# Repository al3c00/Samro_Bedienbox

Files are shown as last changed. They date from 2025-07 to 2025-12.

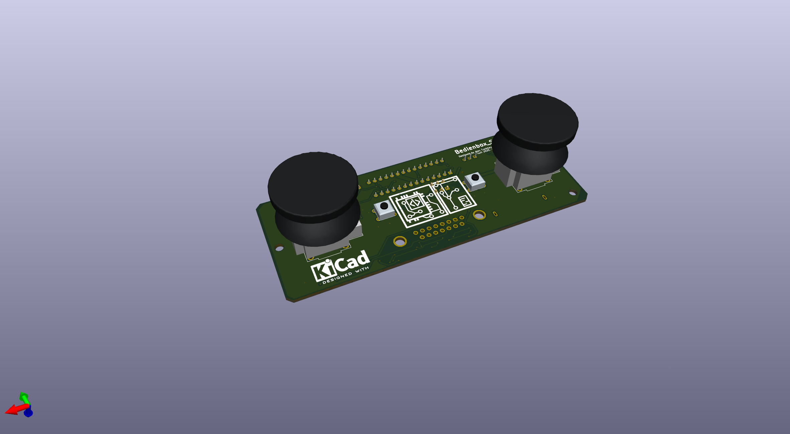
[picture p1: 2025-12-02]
hardware/ansicht_oben.png

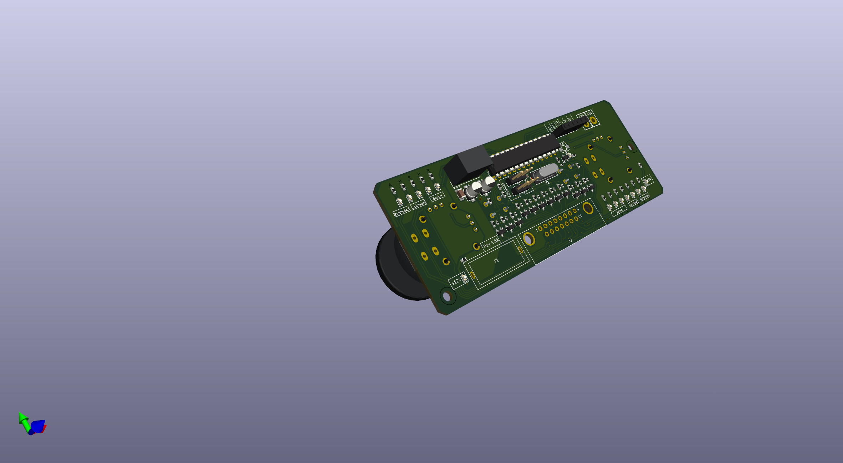
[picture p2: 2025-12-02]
hardware/ansicht_unten.png

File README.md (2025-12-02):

# Samro_Bedienbox

## Übersicht:
Dieses Repository beinhaltet PCB-Daten (Gerber-Dateien und ein KiCAD-Projekt) sowie den Quellcode für die Programmierung des verwendeten ATMega328.

## Hintergrund:
Dies ist eine Steuerungsbox, die die bestehende Steuerung eines Samro Offsett KK Kartoffelvollernters ergänzt. Die Standardbedienung der 20 Jahre alten Maschine weicht von moderneren Bedienunglayouts ab. Um mir als Fahrer, der bei einem Lohnunternehmer im Herbst etliche Stunden mit neuen Maschinen fährt, jeweils den Wechsel der Maschine zu erleichtern, wurde diese Bedienung konstruiert. Die Funktionsbelegung ähnelt der Grimme GBX 800, wie sie beim Lohnunternehmen Wyss-Wyss verwendet wird.

## Funktion:
### Übersicht
Die Kontaktschalter der Samro-Bedienbox ziehen das Signal auf Masse. Die Hardware der Box erkennt dies und sendet ein entprechendes Signal an die Hauptplatine der Maschine. Die zusätzliche Bedienbox ergänzt diese FUnktionsweise. An die Signalpins der Kontaktschalter werden Kabel gelötet welche mit der zusätzlichen Box verbunden werden. 
### Detailiert
Beispielhafte Darstellung der Funktionsweise an einer Funktion:

```mermaid
  graph TD;
  Pin_MC_Samro-->Joystick;
  Joystick-->2N7002_zusätzliche_Box;
  ATMega328-->2N7002_zusätzliche_Box;
  2N7002_zusätzliche_Box-->Masse;
  Joystick-->Masse;

style Joystick fill:#4CED57
```

Um die Verwendung von ISP auf der Platine zun ermöglichen dürfen ISP-Pins des ATMega328 nicht belegt werden. Dies hat zur Folge, dass nicht alle wichtigen Funktionen der Maschine auf einer zusätzlichen Box belegt werden können. Abhilfe wird mit Jumpern geschaffen. Von zwei ATMega328 Ausgangspins (PD1 und PD2) kann ausgewählt werden, ob das Signal den Bunker oder die Dammaufnahme ansteuern soll. Andere Belegungsänderungen sind während Laufzeit nicht möglich und müssen durch ändern des Quellcodes und Neukompilierung gemacht werden.

## Software:
Es gibt kein seperater Ordner der für den Quellcode benutzt wird. Die .ino-Datei beinhaltet alle Daten. 

## Hardware:
Im Hardware-Ordner finden sich die Schemas, Gerber-Dateien und das dazugehörige KiCAD-Projekt. 

## Programmierung des ATMega328:
### Es gibt viele verschiedene, sehr gute Artikel dazu. Ein Beispiel: https://www.brennantymrak.com/articles/programming-avr-with-arduino

|ATMEga328|Arduino|
|---|---|
|PC6|Pin 10|
|PB5|Pin 13|
|PB4|Pin 12|
|PB3|Pin 11|
+ In IDE (Arduino IDE oder Visual Micro in VS2022), wähle Arduino als ISP
+ Richtiger Chip mit korrekter Clock-Speed

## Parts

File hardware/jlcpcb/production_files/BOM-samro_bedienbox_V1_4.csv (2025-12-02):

Comment | Designator | Footprint | LCSC | Quantity
220 | R1,R10,R14,R17,R23,R24,R25,R26,R32,R36,R37,R4,R9 | R_0402_1005Metric | C1091 | 13
2N7002K | Q1,Q10,Q11,Q12,Q13,Q2,Q3,Q4,Q5,Q6,Q7,Q8,Q9 | SOT-23 | C114458 | 13
16MHz | Y1 | Crystal_SMD_HC49-SD | C12676 | 1
10k | R13,R16,R19,R20,R21,R22,R3,R31,R34,R35,R5,R7,R8,R82,R83,R84 | R_0603_1608Metric | C15401 | 16
20pF | C4,C5 | C_0402_1005Metric | C1554 | 2
100nF | C2 | C_0402_1005Metric | C1581 | 1
LED_Green | D27,D28 | LED_0603_1608Metric | C165982 | 2
ATmega328P-P | U1 | DIP-28_W7.62mm | C16653 | 1
1uF | C1 | C_1206_3216Metric | C1848 | 1
D-Sub_15Pins | J2 | D-SUB-DR-15PCG-AB | C19077347 | 1
LED_Red | D1,D10,D11,D12,D13,D2,D3,D4,D5,D6,D7,D8,D9 | LED_0603_1608Metric | C19171390 | 13
130 | R11,R12,R15,R18,R2,R27,R28,R29,R30,R33,R38,R39,R6,R80 | R_0603_1608Metric | C22796 | 14
15k | R85 | R_0603_1608Metric | C22809 | 1
470 | R79 | R_0603_1608Metric | C23179 | 1
Conn_01x06_Socket | J4 | PinSocket_1x06_P2.54mm_Vertical | C2832269 | 1
10uF | C3,C6 | CP_Elec_4x5.4 | C3343 | 2
Conn_01x03_Pin | J5,J6 | PinHeader_1x03_P2.54mm_Vertical | C49257 | 2
Fuseholder | F1 | Fuseholder_C58066 | C58066 | 1
SW_Push | SW5 | Button_L3.9_W3.0 | C720477 | 1
TSR1-2450E | U4 | Converter_DCDC_TRACO_TSR1-xxxxE_THT |  | 1
~ | U3 | Analog_Thumb_Joystick |  | 1
SW_Button_1 | SW1 | Button_DIP_DTS-62N |  | 1
~ | U2 | Analog_Thumb_Joystick |  | 1
SW_Button_2 | SW2 | Button_DIP_DTS-62N |  | 1

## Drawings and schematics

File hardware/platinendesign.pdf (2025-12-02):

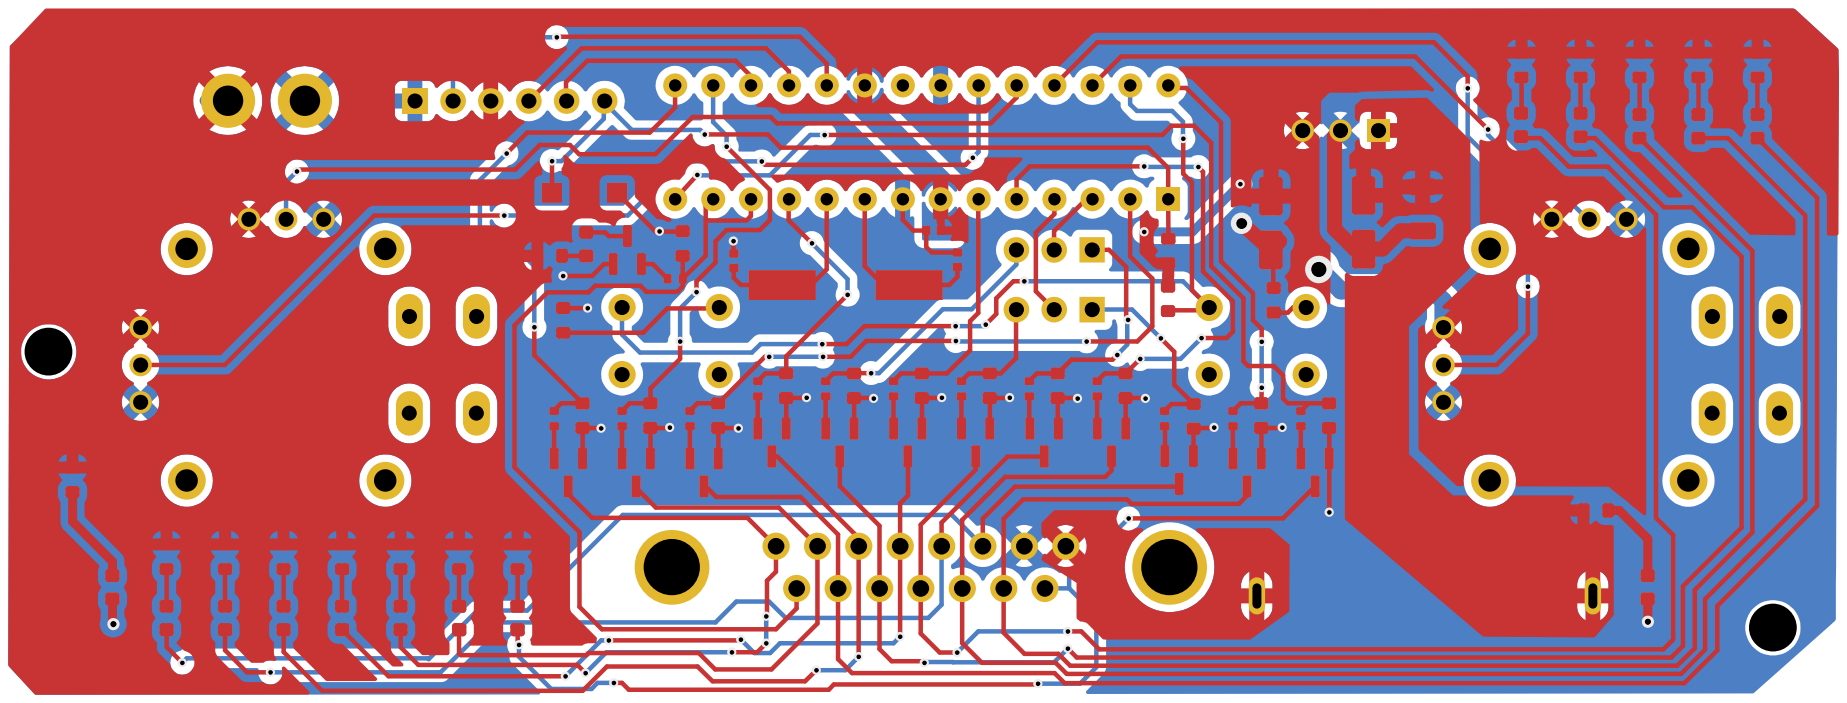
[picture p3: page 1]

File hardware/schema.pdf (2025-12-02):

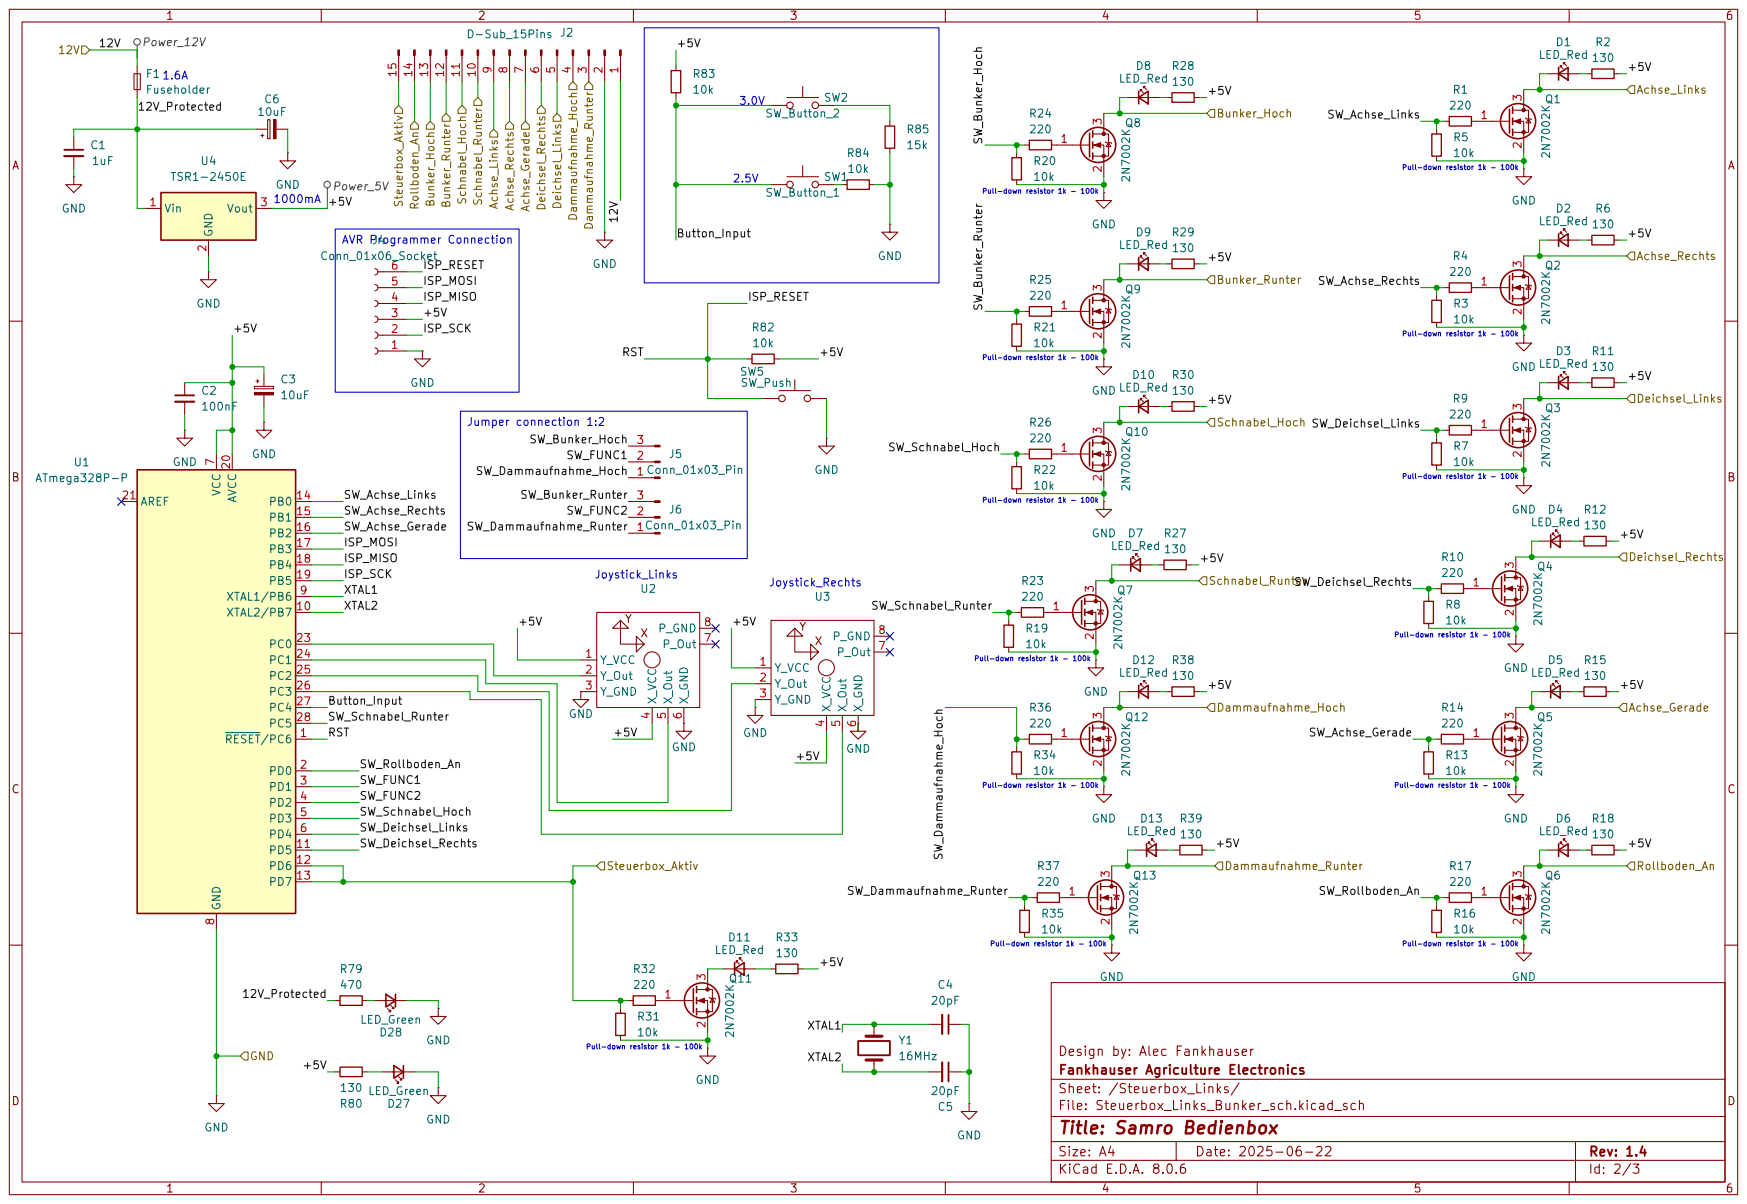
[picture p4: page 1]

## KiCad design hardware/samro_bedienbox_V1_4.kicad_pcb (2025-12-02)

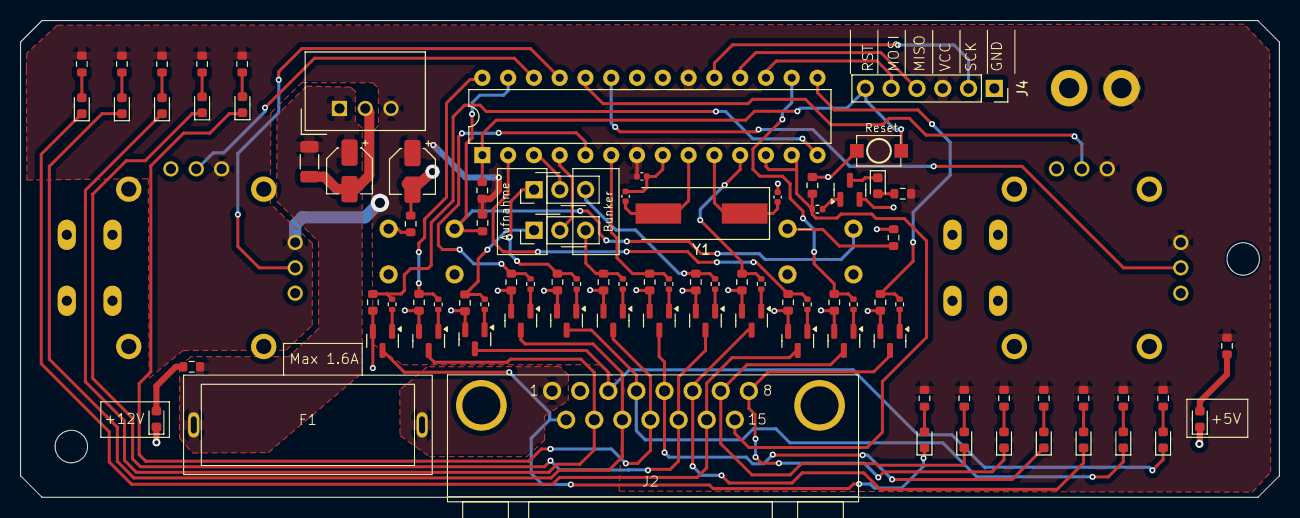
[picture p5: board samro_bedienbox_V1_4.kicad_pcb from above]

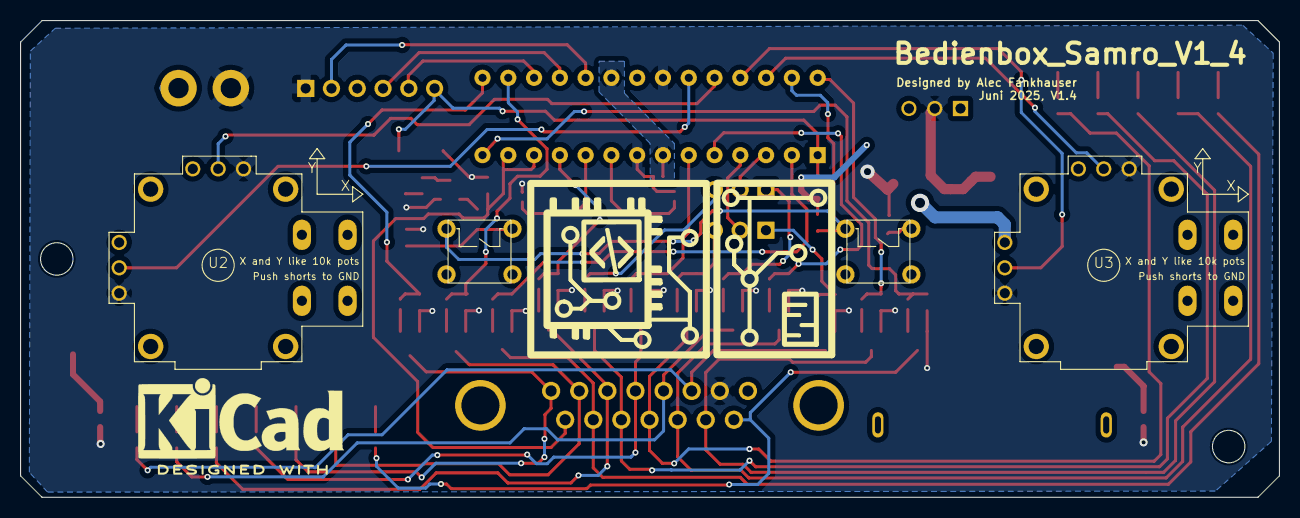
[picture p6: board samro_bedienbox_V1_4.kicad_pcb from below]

Board: 2 copper layers, 124.0 x 47.0 mm, 92 parts (4 on the bottom side), 73 nets.

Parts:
C1: 1uF; C_1206_3216Metric
C2: 100nF; C_0402_1005Metric
C3, C6: 10uF; CP_Elec_4x5.4
C4, C5: 20pF; C_0402_1005Metric
D1, D2, D3, D4, D5, D6, D7, D8, D9, D10, D11, D12, D13: LED_Red; LED_0603_1608Metric
D27, D28: LED_Green; LED_0603_1608Metric
F1: Fuseholder; Fuseholder_C58066
J2: D-Sub_15Pins; D-SUB-DR-15PCG-AB
J4: Conn_01x06_Socket; PinSocket_1x06_P2.54mm_Vertical
J5, J6: Conn_01x03_Pin; PinHeader_1x03_P2.54mm_Vertical
Q1, Q2, Q3, Q4, Q5, Q6, Q7, Q8, Q9, Q10, Q11, Q12, Q13: 2N7002K; SOT-23
R1, R4, R9, R10, R14, R17, R23, R24, R25, R26, R32, R36, R37: 220; R_0402_1005Metric
R2, R6, R11, R12, R15, R18, R27, R28, R29, R30, R33, R38, R39, R80: 130; R_0603_1608Metric
R3, R5, R7, R8, R13, R16, R19, R20, R21, R22, R31, R34, R35, R82, R83, R84: 10k; R_0603_1608Metric
R79: 470; R_0603_1608Metric
R85: 15k; R_0603_1608Metric
SW1: SW_Button_1; Button_DIP_DTS-62N
SW2: SW_Button_2; Button_DIP_DTS-62N
SW5: SW_Push; Button_L3.9_W3.0
U1: ATmega328P-P; DIP-28_W7.62mm
U2, U3: Analog_Thumb_Joystick
U4: TSR1-2450E; Converter_DCDC_TRACO_TSR1-xxxxE_THT
Y1: 16MHz; Crystal_SMD_HC49-SD

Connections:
/Signal.+12V: F1.2, J2.1
/Signal.Achse_Gerade: D5.1 (K), J2.7, Q5.3 (D)
/Signal.Achse_Links: D1.1 (K), J2.9, Q1.3 (D)
/Signal.Achse_Rechts: D2.1 (K), J2.8, Q2.3 (D)
/Signal.Bunker_Hoch: D8.1 (K), J2.13, Q8.3 (D)
/Signal.Bunker_Runter: D9.1 (K), J2.12, Q9.3 (D)
/Signal.Dammaufnahme_Hoch: D12.1 (K), J2.4, Q12.3 (D)
/Signal.Dammaufnahme_Runter: D13.1 (K), J2.3, Q13.3 (D)
/Signal.Deichsel_Links: D3.1 (K), J2.5, Q3.3 (D)
/Signal.Deichsel_Rechts: D4.1 (K), J2.6, Q4.3 (D)
/Signal.Rollboden_An: D6.1 (K), J2.14, Q6.3 (D)
/Signal.Schnabel_Hoch: D10.1 (K), J2.11, Q10.3 (D)
/Signal.Schnabel_Runter: D7.1 (K), J2.10, Q7.3 (D)
/Signal.Steuerbox_Aktiv: J2.15, R31.1, R32.1, U1.12 (PD6), U1.13 (PD7)
/Steuerbox_Links/12V_Protected: C1.1, C6.1, F1.1, R79.1, U4.1 (Vin)
/Steuerbox_Links/+5V: C2.1, C3.1, J4.3, R2.2, R6.2, R11.2, R12.2, R15.2, R18.2, R27.2, R28.2, R29.2, R30.2, R33.2, R38.2, R39.2, R80.2, R82.2, R83.2, U1.7 (VCC), U1.20 (AVCC), U2.1 (Y_VCC), U2.4 (X_VCC), U3.1 (Y_VCC), U3.4 (X_VCC), U4.3 (Vout)
/Steuerbox_Links/Button_Input: R83.1, SW1.1, SW2.1, U1.27 (PC4)
/Steuerbox_Links/ISP_MISO: J4.4, U1.18 (PB4)
/Steuerbox_Links/ISP_MOSI: J4.5, U1.17 (PB3)
/Steuerbox_Links/ISP_RESET: J4.6, R82.1, SW5.1, U1.1 (~RESET/PC6)
/Steuerbox_Links/ISP_SCK: J4.2, U1.19 (PB5)
/Steuerbox_Links/SW_Achse_Gerade: R13.1, R14.1, U1.16 (PB2)
/Steuerbox_Links/SW_Achse_Links: R1.1, R5.1, U1.14 (PB0)
/Steuerbox_Links/SW_Achse_Rechts: R3.1, R4.1, U1.15 (PB1)
/Steuerbox_Links/SW_Bunker_Hoch: J5.3, R20.1, R24.1
/Steuerbox_Links/SW_Bunker_Runter: J6.3, R21.1, R25.1
/Steuerbox_Links/SW_Dammaufnahme_Hoch: J5.1, R34.1, R36.1
/Steuerbox_Links/SW_Dammaufnahme_Runter: J6.1, R35.1, R37.1
/Steuerbox_Links/SW_Deichsel_Links: R7.1, R9.1, U1.6 (PD4)
/Steuerbox_Links/SW_Deichsel_Rechts: R8.1, R10.1, U1.11 (PD5)
/Steuerbox_Links/SW_FUNC1: J5.2, U1.3 (PD1)
/Steuerbox_Links/SW_FUNC2: J6.2, U1.4 (PD2)
/Steuerbox_Links/SW_Rollboden_An: R16.1, R17.1, U1.2 (PD0)
/Steuerbox_Links/SW_Schnabel_Hoch: R22.1, R26.1, U1.5 (PD3)
/Steuerbox_Links/SW_Schnabel_Runter: R19.1, R23.1, U1.28 (PC5)
/Steuerbox_Links/XTAL1: C4.2, U1.9 (XTAL1/PB6), Y1.2
/Steuerbox_Links/XTAL2: C5.2, U1.10 (XTAL2/PB7), Y1.1
GND: C1.2, C2.2, C3.2, C4.1, C5.1, C6.2, D27.1 (K), D28.1 (K), J2.2, J4.1, Q1.2 (S), Q2.2 (S), Q3.2 (S), Q4.2 (S), Q5.2 (S), Q6.2 (S), Q7.2 (S), Q8.2 (S), Q9.2 (S), Q10.2 (S), Q11.2 (S), Q12.2 (S), Q13.2 (S), R3.2, R5.2, R7.2, R8.2, R13.2, R16.2, R19.2, R20.2, R21.2, R22.2, R31.2, R34.2, R35.2, R84.1, R85.2, SW5.2, U1.8 (GND), U1.22 (GND), U2.3 (Y_GND), U2.6 (X_GND), U3.3 (Y_GND), U3.6 (X_GND), U4.2 (GND)
unnamed: D1.2 (A), R2.1
unnamed: D2.2 (A), R6.1
unnamed: D3.2 (A), R11.1
unnamed: D4.2 (A), R12.1
unnamed: D5.2 (A), R15.1
unnamed: D6.2 (A), R18.1
unnamed: D7.2 (A), R27.1
unnamed: D8.2 (A), R28.1
unnamed: D9.2 (A), R29.1
unnamed: D10.2 (A), R30.1
unnamed: D11.2 (A), R33.1
unnamed: D11.1 (K), Q11.3 (D)
unnamed: D12.2 (A), R38.1
unnamed: D13.2 (A), R39.1
unnamed: D27.2 (A), R80.1
unnamed: D28.2 (A), R79.2
unnamed: Q1.1 (G), R1.2
unnamed: Q2.1 (G), R4.2
unnamed: Q3.1 (G), R9.2
unnamed: Q4.1 (G), R10.2
unnamed: Q5.1 (G), R14.2
unnamed: Q6.1 (G), R17.2
unnamed: Q7.1 (G), R23.2
unnamed: Q8.1 (G), R24.2
unnamed: Q9.1 (G), R25.2
unnamed: Q10.1 (G), R26.2
unnamed: Q11.1 (G), R32.2
unnamed: Q12.1 (G), R36.2
unnamed: Q13.1 (G), R37.2
unnamed: R84.2, SW1.2
unnamed: R85.1, SW2.2
unnamed: U1.23 (PC0), U2.2 (Y_Out)
unnamed: U1.24 (PC1), U2.5 (X_Out)
unnamed: U1.25 (PC2), U3.2 (Y_Out)
unnamed: U1.26 (PC3), U3.5 (X_Out)

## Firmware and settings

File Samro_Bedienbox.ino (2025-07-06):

/*
 Name:		Samro_Bedienbox.ino
 Created:	08.06.2025 23:10:32
 Author:	Alec Fankhauser
*/

#include "Arduino.h"




//Use "Release", otherwise the ATMega328P will try to establish a serial connection, rendering _Func1 unusuable.

//Version Samro_Bedienbox_V1_4





	//define Inputs
#define _Joystick_Left_X	A1
#define _Joystick_Left_Y	A0
#define _Joystick_Right_X	A3
#define _Joystick_Right_Y	A2
#define _Button_Input		A4
#define _Signal_Active_IN	7



//define Outputs
#define _RollbodenAn		0
#define _Func1				1 //Dammaufnahme oder Bunker Hoch/Runter
#define _Func2				2 //Dammaufnahme oder Bunker Hoch/Runter
#define _Deichsel_Links		4
#define _Deichsel_Rechts	5
#define _Achse_Links		8
#define _Achse_Rechts		9
#define _Achse_Gerade		10
#define _Schnabel_Runter	A5
#define _Schnabel_Hoch		3
#define _Signal_Active_OUT	6			


//Analog Inputs 0 - 1024
//Analog Active 0 - 204 and 820 - 1024
uint16_t Joystick_LowActive_Value = 204;
uint16_t Joystick_HighActive_Value = 820;

//Value: 1024/5*xV (Threshhold = 50)
//Button1 pressed: _Button_Input = 2.5V
//Button2 pressed: _Button_Input = 3.0V
//Both: 1.8V
uint16_t Button_1_LowActive_Value = 462;
uint16_t Button_1_HighActive_Value = 562;

uint16_t Button_2_LowActive_Value = 564;
uint16_t Button_2_HighActive_Value = 800;

uint16_t Button_BOTH_LowActive_Value = 318;
uint16_t Button_BOTH_HighActive_Value = 408;

struct Inputs
{
	uint16_t	Buttons_Value; //2.5V = SW1, 3V = SW2, 1.88V = SW1 & SW2
	uint16_t	Buttons_Measured;

	uint16_t	Joystick_Left_X_Value;
	uint16_t	Joystick_Left_X_Measured;
	uint16_t	Joystick_Left_Y_Value;
	uint16_t	Joystick_Left_Y_Measured;

	uint16_t	Joystick_Right_X_Value;
	uint16_t	Joystick_Right_X_Measured;
	uint16_t	Joystick_Right_Y_Value;
	uint16_t	Joystick_Right_Y_Measured;
};
Inputs input;


uint16_t last_time;
uint16_t interval_time;

bool loop_New_Values = false;

// the setup function runs once when you press reset or power the board
void setup() 
{
	//Setup Inputs
	{
		pinMode(_Joystick_Left_X, INPUT);
		pinMode(_Joystick_Left_Y, INPUT);
		pinMode(_Joystick_Right_X, INPUT);
		pinMode(_Joystick_Right_Y, INPUT);
		pinMode(_Button_Input, INPUT);
		pinMode(_Signal_Active_IN, INPUT);

		pinMode(_Func1, OUTPUT);
		pinMode(_Func2, OUTPUT);
		pinMode(_Deichsel_Links, OUTPUT);
		pinMode(_Deichsel_Rechts, OUTPUT);
		pinMode(_Achse_Links, OUTPUT);
		pinMode(_Achse_Rechts, OUTPUT);
		pinMode(_Achse_Gerade, OUTPUT);
		pinMode(_Schnabel_Hoch, OUTPUT);
		pinMode(_Schnabel_Runter, OUTPUT);
		pinMode(_RollbodenAn, OUTPUT);
		pinMode(_Signal_Active_OUT, OUTPUT);
	}

	last_time = 0;
	interval_time = 100;

}

// the loop function runs over and over again until power down or reset
void loop()
{
	


	uint16_t current_time = millis();
	if (current_time - last_time >= interval_time)
	{
		last_time = current_time;

		//Read left joystick
		if ((input.Joystick_Left_X_Measured = analogRead(_Joystick_Left_X)) != input.Joystick_Left_X_Value)
		{
			loop_New_Values = true;
		}
		if ((input.Joystick_Left_Y_Measured = analogRead(_Joystick_Left_Y)) != input.Joystick_Left_Y_Value)
		{
			loop_New_Values = true;
		}
		//Read right joystick
		if ((input.Joystick_Right_X_Measured = analogRead(_Joystick_Right_X)) != input.Joystick_Right_X_Value)
		{
			loop_New_Values = true;
		}
		if ((input.Joystick_Right_Y_Measured = analogRead(_Joystick_Right_Y)) != input.Joystick_Right_Y_Value)
		{
			loop_New_Values = true;
		}
		//Read button 
		if ((input.Buttons_Measured = analogRead(_Button_Input)) != input.Buttons_Value)
		{
			loop_New_Values = true;
		}
		
		
		
		//If there are any new Input Values, go refresh everything
		if (loop_New_Values)
		{
		
			//Buttons
			{
				if (input.Buttons_Measured > Button_1_LowActive_Value && input.Buttons_Measured < Button_1_HighActive_Value)
				{
					digitalWrite(_RollbodenAn, HIGH);
					digitalWrite(_Achse_Gerade, LOW);
				}

				else if (input.Buttons_Measured > Button_2_LowActive_Value && input.Buttons_Measured < Button_2_HighActive_Value)
				{
					digitalWrite(_Achse_Gerade, HIGH);
					digitalWrite(_RollbodenAn, LOW);
				}

				else if (input.Buttons_Measured > Button_BOTH_LowActive_Value && input.Buttons_Measured < Button_BOTH_HighActive_Value)
				{
					digitalWrite(_Achse_Gerade, HIGH);
					digitalWrite(_RollbodenAn, HIGH);
				}
				else
				{
					digitalWrite(_Achse_Gerade, LOW);
					digitalWrite(_RollbodenAn, LOW);
				}

			}



			//Achse
			{
				if (input.Joystick_Left_X_Measured < Joystick_LowActive_Value)
				{
					digitalWrite(_Deichsel_Links, HIGH);
				}
				else if (input.Joystick_Left_X_Measured >= Joystick_LowActive_Value && input.Joystick_Left_X_Measured < Joystick_HighActive_Value)
				{
					digitalWrite(_Deichsel_Links, LOW);
					digitalWrite(_Deichsel_Rechts, LOW);
				}
				else if (input.Joystick_Left_X_Measured > Joystick_HighActive_Value)
				{
					digitalWrite(_Deichsel_Rechts, HIGH);
				}


			}


			//Deichsel
			{
				if (input.Joystick_Left_Y_Measured < Joystick_LowActive_Value)
				{
					digitalWrite(_Achse_Links, HIGH);
				}
				else if (input.Joystick_Left_Y_Measured >= Joystick_LowActive_Value && input.Joystick_Left_Y_Measured < Joystick_HighActive_Value)
				{
					digitalWrite(_Achse_Links, LOW);
					digitalWrite(_Achse_Rechts, LOW);
				}
				else if (input.Joystick_Left_Y_Measured > Joystick_HighActive_Value)
				{
					digitalWrite(_Achse_Rechts, HIGH);
				}
			}

			//Func--Dammaufnahme oder Bunker
			{
				if (input.Joystick_Right_Y_Measured < Joystick_LowActive_Value)
				{
					digitalWrite(_Func2, HIGH);
				}
				else if (input.Joystick_Right_Y_Measured >= Joystick_LowActive_Value && input.Joystick_Right_Y_Measured < Joystick_HighActive_Value)
				{
					digitalWrite(_Func1, LOW);
					digitalWrite(_Func2, LOW);
				}
				else if (input.Joystick_Right_Y_Measured > Joystick_HighActive_Value)
				{
					digitalWrite(_Func1, HIGH);
				}
			}

			//Schnabel
			{
				if (input.Joystick_Right_X_Measured < Joystick_LowActive_Value)
				{
					digitalWrite(_Schnabel_Runter, HIGH);
				}
				else if (input.Joystick_Right_X_Measured >= Joystick_LowActive_Value && input.Joystick_Right_X_Measured < Joystick_HighActive_Value)
				{
					digitalWrite(_Schnabel_Runter, LOW);
					digitalWrite(_Schnabel_Hoch, LOW);
				}
				else if (input.Joystick_Right_X_Measured > Joystick_HighActive_Value)
				{
					digitalWrite(_Schnabel_Hoch, HIGH);
				}
			}

			input.Buttons_Value = input.Buttons_Measured;
			input.Joystick_Left_X_Value = input.Joystick_Left_X_Measured;
			input.Joystick_Left_Y_Value = input.Joystick_Left_Y_Measured;
			input.Joystick_Right_X_Value = input.Joystick_Right_X_Measured;
			input.Joystick_Right_Y_Value = input.Joystick_Right_Y_Measured;

			loop_New_Values = false;


		}

	}
	


/*
//Debugging, set all outputs to high to measure amps: Result is 0.14A

digitalWrite(_Achse_Gerade, HIGH); //Set Achse to straight position
digitalWrite(_Func1, HIGH);
digitalWrite(_Func2, HIGH); //Set Func1 and Func2 to high (Dammaufnahme or Bunker)
digitalWrite(_Deichsel_Links, HIGH);
digitalWrite(_Deichsel_Rechts, HIGH); //Set Deichsel to straight position
digitalWrite(_Schnabel_Hoch, HIGH);
digitalWrite(_Schnabel_Runter, HIGH); //Set Schnabel to straight position
digitalWrite(_RollbodenAn, HIGH);
digitalWrite(_Achse_Links, HIGH);
digitalWrite(_Achse_Rechts, HIGH); //Set Achse to straight position
*/

}

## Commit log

2025-06-23 .gitattributes, .gitignore und README.md hinzufügen.
2025-07-03 button input correct
2025-07-06 switched Rollboden und Achse_Gerade
2025-12-02 Update and rename Steuerbox_Links_Bunker_sch.kicad_sch to hardware/Steuerbox_Links_Bunker_sch.kicad_sch
    [Steuerbox_Links_Bunker_sch.kicad_sch]
2025-12-02 Update and rename
    [samro_bedienbox_V1_4.kicad_sch]
2025-12-02 Add HW_version_1_4_files
    [samro_bedienbox_V1_4.kicad_pcb, samro_bedienbox_V1_4.kicad_sch]
2025-12-02 Revise ATmega328 to Arduino pin mapping format
    Updated the pin mapping table for ATmega328 and Arduino.
2025-12-02 Refactor ATMEga328 to Arduino pin mapping table
    Updated pin mapping table format for clarity.
2025-12-02 Detailierter Funktionsbeschrieb
    Updated the diagram and added notes on ISP pin usage and jumper functionality.
2025-12-02 Fix typos and improve readability in README
    Korrigiert Rechtschreibfehler und verbessert die Lesbarkeit im README.
